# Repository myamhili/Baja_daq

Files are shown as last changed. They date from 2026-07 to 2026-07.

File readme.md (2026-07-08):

# Baja SAE Central Data Acquisition (DAQ) Node

A custom, ruggedized telemetry and data logging PCB engineered for the University of Waterloo Baja SAE racing vehicle. 

Unlike standard microcontroller breakout boards, this DAQ node is designed to survive the harsh electrical and mechanical environment of an automotive chassis. It features a 4-layer load-dump protected layout, dedicated hardware for high-speed logging, and a real-time FreeRTOS firmware architecture.

baja_daq

bajafirmwarepic
LL9DJzj04BtlhnXn9L0uzD93XS64HbL8iSs7r5JLr1b_DFQkjJDBe5N_UtVN8GcNnBFllT6RDtF1WbPStobffIEunDy8QN87qzRs6xG49p2rH5cno67nJFQvfOrIl6xrW1PxA4q_64rQSddrUakbeAuxEg1mWokpQNKD5NPCIWrOhh4cECf9ix7m0HweQKild-d12H_1NmNmFKcl89qdIvq

## ⚙️ Hardware Architecture
* **Microcontroller:** STM32F405RGTx (ARM Cortex-M4) handling real-time sensor polling and SDIO data pipelines.
* **PCB Stackup:** 4-Layer board (Signal, Solid Ground, Split Power, Signal) optimized for signal integrity, return paths, and thermal dissipation.

## 🔋 Automotive-Grade Power System
The board interfaces directly with the vehicle's 12V starter battery and is hardened against off-road electrical surges:
* **Surge Protection:** Input clamped by an SMAJ15A TVS Diode with localized solid copper pour spillways to instantly shunt 60V load dumps to the ground plane.
* **Analog Rail (5V):** L7805 linear regulator feeding suspension and rotary sensors with a clean, heavily filtered reference voltage.
* **Digital Rail (3.3V):** AMS1117 LDO isolated with dedicated bulk tantalum/ceramic decoupling arrays to prevent STM32 brownouts under severe chassis vibration.

## 📡 Sensor & Communication Interfaces
* **Vehicle Network:** CAN Bus (TJA1051T transceiver) acting as a non-blocking broadcast node for dashboard telemetry, timed via an 8MHz external crystal.
* **Inertial Tracking:** On-board 6-axis IMU (ISM330DHCX) communicating via high-speed SPI.
* **Telemetry Logging:** MicroSD card slot wired via 4-bit SDIO with 47k pull-up stability arrays for reliable 100Hz writes.
* **External I/O (Locking Molex Connectors):** * Front & Rear Suspension Travel (Generic 3-pin ADC)
    * Engine & Secondary CVT RPM (Hardware Timers / Input Capture)
    * Belt Temperature Probes (I2C)

## 💻 Firmware Design (FreeRTOS)
The system runs a custom C firmware utilizing the STM32 HAL and CMSIS-RTOS.
* **Decoupled Logging:** A high-priority sensor task handles SPI/I2C polling and mathematically derives ground speed from timer deltas. Data is formatted and pushed to a FreeRTOS queue.
* **Non-Blocking File I/O:** A lower-priority FatFs SD Writer task pulls from the queue to write to the MicroSD card, ensuring that standard file-system latency does not freeze the 100Hz real-time data gathering loop.
* **Data Protection:** Implements an automated 15-minute file rotation state machine to prevent total file corruption in the event of a sudden power loss or rollover.

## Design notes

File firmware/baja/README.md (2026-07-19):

# Baja DAQ firmware

The firmware samples vehicle data at 100 Hz. Logging starts at 800 RPM, stops
after RPM remains below 500 for one second, rotates files every 15 minutes, and
syncs the active file at least once per second. Existing `RUN_####.CSV` files
are never overwritten.

## Sensor interfaces

- MLX90614 object temperature: I2C1, address `0x5A`, PB6/PB7, 100 kHz.
- ISM330DHCX: SPI1 mode 0, PB1 chip select, 104 Hz, +/-4 g and +/-500 dps.
- Suspension position: ADC1 channels 2 and 3 with a 32-sample startup zero.
- Engine and secondary speed: TIM5 input capture with a 500 ms pulse timeout.

CSV `Sensor_Status` bit 0 marks temperature valid and bit 1 marks IMU data
valid. Invalid values must be ignored even if the numeric field contains the
last successful sample.

## CAN frames

- `0x100`, 100 Hz: engine RPM (big-endian uint16), speed, temperature, flags.
  Temperature `0xFF` means invalid. Flag bits 0-3 are high temperature, high
  RPM, temperature invalid, and IMU invalid.
- `0x101`, 1 Hz: saturated uint8 counters for queue drops, SD mount/write/sync
  failures, MLX failures, IMU failures, CAN drops, and CAN bus-off events.

CAN is configured for 333.333 kbit/s from the 16 MHz APB1 clock.

## Bench validation

Before vehicle use, verify sensor axis orientation, pulses per revolution,
gearbox ratio, temperature field of view, CAN bitrate, SD-card removal, and
sudden-power-loss recovery on the assembled board.

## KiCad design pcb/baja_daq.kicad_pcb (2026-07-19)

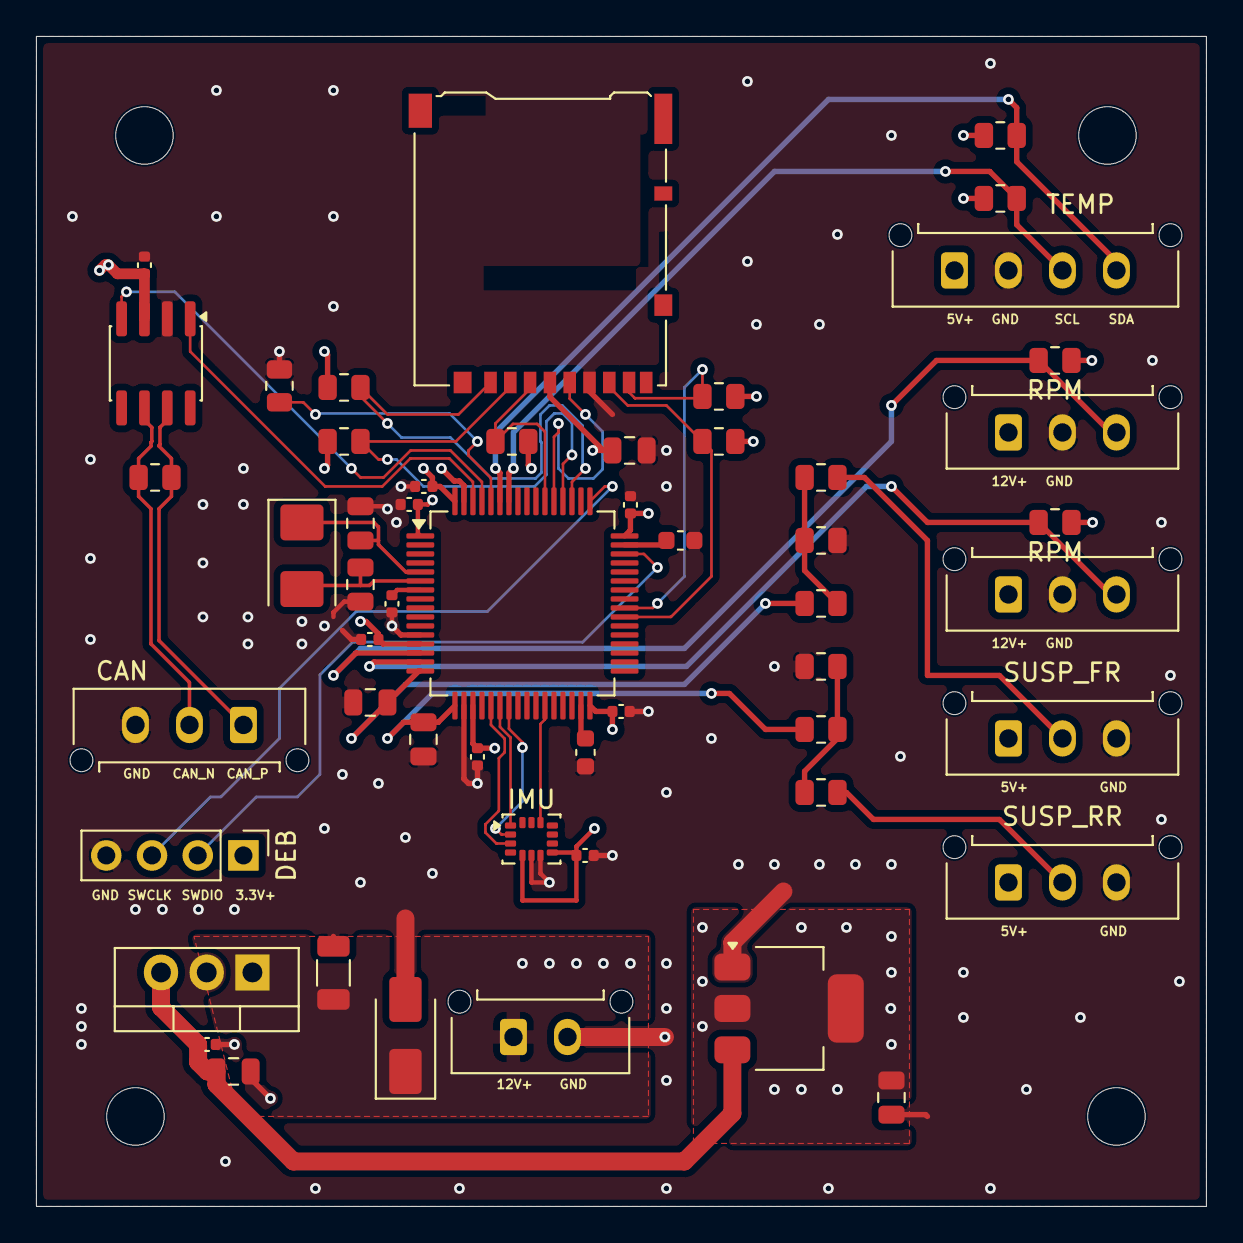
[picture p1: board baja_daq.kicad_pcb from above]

Board: 4 copper layers, 65.0 x 65.0 mm, 57 parts (0 on the bottom side), 36 nets.

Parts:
C1, C2: 22pF; C_0805_2012Metric
C3, C4: 4.7uF; C_0805_2012Metric
C5, C6, C7, C8, C9, C10, C13, C14, C15, C19: 100nF; C_0402_1005Metric
C11, C12: 2.2uF; C_0603_1608Metric
C16, C18: 10uF; C_0805_2012Metric
C17: 10uF; C_1206_3216Metric
C20: 22uF; C_0805_2012Metric
CAN: Conn_01x03; Molex_Micro-Fit_3.0_43650-0315_1x03_P3.00mm_Vertical
D1: SMAJ15A; D_SMA
DEB: Conn_01x04; PinHeader_1x04_P2.54mm_Vertical
H1, H2, H3, H4: MountingHole; MountingHole_3.2mm_M3
IMU: ISM330DHCX; LGA-14_3x2.5mm_P0.5mm_LayoutBorder3x4y
J1: Micro_SD_Card; microSD_HC_Hirose_DM3AT-SF-PEJM5
J3, J4: Conn_01x03; Molex_Micro-Fit_3.0_43650-0315_1x03_P3.00mm_Vertical
J7: Conn_01x02; Molex_Micro-Fit_3.0_43650-0215_1x02_P3.00mm_Vertical
R1: 10k; R_0805_2012Metric
R2, R3, R4, R5, R6: 47k; R_0805_2012Metric
R7: 120Ω; R_0805_2012Metric
R8, R9: 2.2k; R_0805_2012Metric
R12, R15: 1.7k; R_0805_2012Metric
R13, R16: 3.3k; R_0805_2012Metric
R14, R17: 1k; R_0805_2012Metric
RPM: 10k; R_0805_2012Metric
RPM#2: 10k; R_0805_2012Metric
SUSP_FR: Conn_01x03; Molex_Micro-Fit_3.0_43650-0315_1x03_P3.00mm_Vertical
SUSP_RR: Conn_01x03; Molex_Micro-Fit_3.0_43650-0315_1x03_P3.00mm_Vertical
TEMP: Conn_01x04; Molex_Micro-Fit_3.0_43650-0415_1x04_P3.00mm_Vertical
U1: STM32F405RGTx; LQFP-64_10x10mm_P0.5mm
U2: TJA1051T; SOIC-8_3.9x4.9mm_P1.27mm
U4: L7805; TO-220-3_Vertical
U5: AMS1117-3.3; SOT-223-3_TabPin2
Y1: 8MHz; Crystal_SMD_5032-2Pin_5.0x3.2mm

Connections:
+3V3_DIG: C5.1, C6.1, C7.1, C8.1, C9.1, C10.1, C14.1, C16.1, C20.1, DEB.1, IMU.5, IMU.8, J1.4, R2.1, R3.1, R4.1, R5.1, R6.1, R8.1, R9.1, RPM.1, RPM#2.1, U1.1, U1.13, U1.19, U1.32, U1.48, U1.64, U5.2
+5V_ANA: C15.1, C18.1, C19.1, SUSP_FR.1, SUSP_RR.1, TEMP.1, U2.3, U4.3, U5.3
+12V_BATT: C17.1, D1.1, J3.1, J4.1, J7.1, U4.1
CAN_N: CAN.2, R7.2, U2.6
CAN_P: CAN.1, R7.1, U2.7
GND: C1.2, C2.2, C3.2, C4.2, C5.2, C6.2, C7.2, C8.2, C9.2, C10.2, C11.2, C12.2, C13.2, C14.2, C15.2, C16.2, C17.2, C18.2, C19.2, C20.2, CAN.3, D1.2, DEB.4, IMU.6, IMU.7, J1.6, J3.2, J4.2, J7.2, R1.2, R13.2, R16.2, SUSP_FR.3, SUSP_RR.3, TEMP.2, U1.12, U1.18, U1.63, U2.2, U4.2, U5.1
I2C_SCL: R8.2, TEMP.3, U1.58
I2C_SDA: R9.2, TEMP.4, U1.59
unnamed: R1.1, U1.60
unnamed: DEB.2, U1.46
unnamed: DEB.3, U1.49
unnamed: C1.1, U1.5, Y1.1
unnamed: C2.1, U1.6, Y1.2
unnamed: J1.7, R2.2, U1.39
unnamed: J1.8, R3.2, U1.40
unnamed: J1.1, R4.2, U1.51
unnamed: J1.2, R5.2, U1.52
unnamed: J1.5, U1.53
unnamed: J1.3, R6.2, U1.54
unnamed: U1.62, U2.1
unnamed: U1.61, U2.4
unnamed: C11.1, U1.31
unnamed: C12.1, U1.47
unnamed: C13.1, U1.7
RPM_ENG: J3.3, RPM.2, U1.14
RPM_SEC: J4.3, RPM#2.2, U1.15
SPI_CS: IMU.12, U1.27
SPI_MISO: IMU.1, U1.22
SPI_MOSI: IMU.2, U1.23
SPI_SCK: IMU.3, U1.21
SUSP_FR_DIV: R12.2, R13.1, R14.1
SUSP_FR_FLT: C3.1, R14.2, U1.16
SUSP_FR_RAW: R12.1, SUSP_FR.2
SUSP_RR_DIV: R15.2, R16.1, R17.1
SUSP_RR_FLT: C4.1, R17.2, U1.17
SUSP_RR_RAW: R15.1, SUSP_RR.2

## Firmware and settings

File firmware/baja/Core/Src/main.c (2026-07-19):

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
/* Includes ------------------------------------------------------------------*/
#include "main.h"
#include "cmsis_os.h"
#include "adc.h"
#include "can.h"
#include "dma.h"
#include "fatfs.h"
#include "i2c.h"
#include "iwdg.h"
#include "sdio.h"
#include "spi.h"
#include "tim.h"
#include "gpio.h"
#include "diagnostics.h"


/* USER CODE BEGIN PV */
// --- FreeRTOS Globals ---
QueueHandle_t csvDataQueue;

volatile uint16_t adc_buffer[2]; // DMA buffer for 2 analog channels
uint32_t susp_zero_front_rt = 0;
uint32_t susp_zero_rear_rt = 0;

volatile uint32_t engine_delta_ticks = 0;
volatile uint32_t secondary_delta_ticks = 0;
volatile uint32_t engine_last_pulse_ms = 0;
volatile uint32_t secondary_last_pulse_ms = 0;
static volatile uint32_t engine_last_capture = 0;
static volatile uint32_t secondary_last_capture = 0;
static volatile uint8_t engine_capture_valid = 0;
static volatile uint8_t secondary_capture_valid = 0;

// --- CAN Globals ---
CAN_TxHeaderTypeDef TxHeader;
uint32_t TxMailbox;
uint8_t TxData[8];
/* USER CODE END PV */

void SystemClock_Config(void);
void MX_FREERTOS_Init(void);
/* USER CODE BEGIN 0 */
// --- Initialization Functions ---
void Init_CAN_Broadcast(void) {
    if (HAL_CAN_Start(&hcan1) != HAL_OK ||
        HAL_CAN_ActivateNotification(&hcan1,
                                     CAN_IT_ERROR |
                                     CAN_IT_BUSOFF) != HAL_OK) {
        Error_Handler();
    }

    // Pre-configure the Transmission Header
    TxHeader.StdId = 0x100;           
    TxHeader.ExtId = 0x00;
    TxHeader.RTR = CAN_RTR_DATA;      
    TxHeader.IDE = CAN_ID_STD;        
    TxHeader.DLC = 8;                 
    TxHeader.TransmitGlobalTime = DISABLE;
}

// Called once in main() before FreeRTOS scheduler starts
void Calibrate_Suspension_Zeros(void) {
    uint32_t front_sum = 0U;
    uint32_t rear_sum = 0U;
    uint32_t sample;

    if (HAL_ADC_Start_DMA(&hadc1, (uint32_t *)adc_buffer, 2) != HAL_OK) {
        Error_Handler();
    }
    HAL_Delay(10);
    for (sample = 0U; sample < 32U; sample++) {
        front_sum += adc_buffer[0];
        rear_sum += adc_buffer[1];
        HAL_Delay(1);
    }
    susp_zero_front_rt = front_sum / 32U;
    susp_zero_rear_rt = rear_sum / 32U;
}

void Start_Timing_Inputs(void) {
    if (HAL_TIM_IC_Start_IT(&htim5, TIM_CHANNEL_1) != HAL_OK) {
        Error_Handler();
    }
    if (HAL_TIM_IC_Start_IT(&htim5, TIM_CHANNEL_2) != HAL_OK) {
        Error_Handler();
    }
}
/* USER CODE END 0 */

/**
  * @brief  The application entry point.
  * @retval int
  */
int main(void)
{

  /* MCU Configuration--------------------------------------------------------*/

  /* Reset of all peripherals, Initializes the Flash interface and the Systick. */
  HAL_Init();

  /* Configure the system clock */
  SystemClock_Config();

  /* Initialize all configured peripherals */
  MX_GPIO_Init();
  MX_DMA_Init();
  MX_ADC1_Init();
  MX_CAN1_Init();
  MX_I2C1_Init();
  MX_SDIO_SD_Init();
  MX_SPI1_Init();
  MX_TIM5_Init();
  MX_FATFS_Init();
  MX_IWDG_Init();
  /* USER CODE BEGIN 2 */
  Calibrate_Suspension_Zeros();
  Start_Timing_Inputs();
  Init_CAN_Broadcast();
  /* USER CODE END 2 */

  /* Call init function for freertos objects (in cmsis_os2.c) */
  MX_FREERTOS_Init();

  /* Start scheduler */
  osKernelStart();

  /* We should never get here as control is now taken by the scheduler */

  /* Infinite loop */
  /* USER CODE BEGIN WHILE */
  while (1)
  {
    /* USER CODE END WHILE */

    /* USER CODE BEGIN 3 */
  }
  /* USER CODE END 3 */
}

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
/* USER CODE BEGIN 4 */
void HAL_TIM_IC_CaptureCallback(TIM_HandleTypeDef *htim)
{
  uint32_t capture;

  if (htim->Instance != TIM5) {
    return;
  }

  if (htim->Channel == HAL_TIM_ACTIVE_CHANNEL_1) {
    capture = HAL_TIM_ReadCapturedValue(htim, TIM_CHANNEL_1);
    if (engine_capture_valid != 0U) {
      engine_delta_ticks = capture - engine_last_capture;
    }
    engine_last_capture = capture;
    engine_last_pulse_ms = HAL_GetTick();
    engine_capture_valid = 1U;
  } else if (htim->Channel == HAL_TIM_ACTIVE_CHANNEL_2) {
    capture = HAL_TIM_ReadCapturedValue(htim, TIM_CHANNEL_2);
    if (secondary_capture_valid != 0U) {
      secondary_delta_ticks = capture - secondary_last_capture;
    }
    secondary_last_capture = capture;
    secondary_last_pulse_ms = HAL_GetTick();
    secondary_capture_valid = 1U;
  }
}

void HAL_CAN_ErrorCallback(CAN_HandleTypeDef *hcan)
{
  uint32_t error = HAL_CAN_GetError(hcan);

  if ((error & HAL_CAN_ERROR_BOF) != 0U) {
    g_diagnostics.can_bus_offs++;
    HAL_CAN_Stop(hcan);
    HAL_CAN_Start(hcan);
    HAL_CAN_ActivateNotification(hcan,
                                  CAN_IT_ERROR |
                                  CAN_IT_BUSOFF);
  }
}

/* USER CODE END 4 */

/**
  * @brief  Period elapsed callback in non blocking mode
  * @note   This function is called  when TIM6 interrupt took place, inside
  * HAL_TIM_IRQHandler(). It makes a direct call to HAL_IncTick() to increment
  * a global variable "uwTick" used as application time base.
  * @param  htim : TIM handle
  * @retval None
  */
void HAL_TIM_PeriodElapsedCallback(TIM_HandleTypeDef *htim)
{
  if (htim->Instance == TIM6)
  {
    HAL_IncTick();
  }
}

/**
  * @brief  This function is executed in case of error occurrence.
  * @retval None
  */
void Error_Handler(void)
{
  /* USER CODE BEGIN Error_Handler_Debug */
  /* User can add his own implementation to report the HAL error return state */
  __disable_irq();
  while (1)
  {
  }
  /* USER CODE END Error_Handler_Debug */
}
#ifdef USE_FULL_ASSERT
/**
  * @brief  Reports the name of the source file and the source line number
  *         where the assert_param error has occurred.
  * @param  file: pointer to the source file name
  * @param  line: assert_param error line source number
  * @retval None
  */
void assert_failed(uint8_t *file, uint32_t line)
{
  /* USER CODE BEGIN 6 */
  /* User can add his own implementation to report the file name and line number,
     ex: printf("Wrong parameters value: file %s on line %d\r\n", file, line) */
  /* USER CODE END 6 */
}
#endif /* USE_FULL_ASSERT */

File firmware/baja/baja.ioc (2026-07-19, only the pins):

Mcu.UserName=STM32F405RGTx
PA0-WKUP.Signal=S_TIM5_CH1
PA1.Signal=S_TIM5_CH2
PA13.Signal=SYS_JTMS-SWDIO
PA14.Signal=SYS_JTCK-SWCLK
PA2.Signal=ADCx_IN2
PA3.Signal=ADCx_IN3
PA5.Signal=SPI1_SCK
PA6.Signal=SPI1_MISO
PA7.Signal=SPI1_MOSI
PB1.GPIO_Label=SPI_CS
PB1.Signal=GPIO_Output
PB6.Signal=I2C1_SCL
PB7.Signal=I2C1_SDA
PB8.Signal=CAN1_RX
PB9.Signal=CAN1_TX
PC10.Signal=SDIO_D2
PC11.Signal=SDIO_D3
PC12.Signal=SDIO_CK
PC8.Signal=SDIO_D0
PC9.Signal=SDIO_D1
PD2.Signal=SDIO_CMD
PH0-OSC_IN.Signal=RCC_OSC_IN
PH1-OSC_OUT.Signal=RCC_OSC_OUT

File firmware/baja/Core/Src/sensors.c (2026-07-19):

#include "sensors.h"
#include "i2c.h"
#include "spi.h"
#include <math.h>

#define MLX90614_ADDRESS          (0x5AU << 1)
#define MLX90614_OBJECT_TEMP_REG  0x07U
#define MLX90614_RETRIES          3U
#define MLX90614_TIMEOUT_MS       20U

#define ISM330_WHO_AM_I_REG       0x0FU
#define ISM330_WHO_AM_I_VALUE     0x6BU
#define ISM330_CTRL1_XL_REG       0x10U
#define ISM330_CTRL2_G_REG        0x11U
#define ISM330_CTRL3_C_REG        0x12U
#define ISM330_OUTX_L_G_REG       0x22U
#define ISM330_SPI_READ           0x80U
#define ISM330_SPI_TIMEOUT_MS     20U
#define RAD_TO_DEG                57.2957795f

static uint8_t Calculate_PEC(const uint8_t *data, uint32_t length)
{
  uint8_t crc = 0U;
  uint32_t i;
  uint8_t bit;

  for (i = 0U; i < length; i++) {
    crc ^= data[i];
    for (bit = 0U; bit < 8U; bit++) {
      crc = (crc & 0x80U) ? (uint8_t)((crc << 1U) ^ 0x07U)
                          : (uint8_t)(crc << 1U);
    }
  }
  return crc;
}

bool MLX90614_Init(void)
{
  return HAL_I2C_IsDeviceReady(&hi2c1, MLX90614_ADDRESS,
                               MLX90614_RETRIES, MLX90614_TIMEOUT_MS) == HAL_OK;
}

bool MLX90614_ReadObjectTemp(float *temperature_c)
{
  uint8_t response[3];
  uint8_t pec_data[5];
  uint16_t raw;
  uint32_t attempt;

  if (temperature_c == NULL) {
    return false;
  }

  for (attempt = 0U; attempt < MLX90614_RETRIES; attempt++) {
    if (HAL_I2C_Mem_Read(&hi2c1, MLX90614_ADDRESS,
                         MLX90614_OBJECT_TEMP_REG, I2C_MEMADD_SIZE_8BIT,
                         response, sizeof(response), MLX90614_TIMEOUT_MS) != HAL_OK) {
      continue;
    }

    pec_data[0] = MLX90614_ADDRESS;
    pec_data[1] = MLX90614_OBJECT_TEMP_REG;
    pec_data[2] = (uint8_t)(MLX90614_ADDRESS | 1U);
    pec_data[3] = response[0];
    pec_data[4] = response[1];
    if (Calculate_PEC(pec_data, sizeof(pec_data)) != response[2]) {
      continue;
    }

    raw = (uint16_t)response[0] | ((uint16_t)response[1] << 8U);
    if ((raw & 0x8000U) != 0U) {
      continue;
    }

    *temperature_c = ((float)raw * 0.02f) - 273.15f;
    return true;
  }

  return false;
}

static bool ISM330_Transfer(uint8_t reg, uint8_t *data, uint16_t length, bool read)
{
  HAL_StatusTypeDef status;
  uint8_t command = read ? (uint8_t)(reg | ISM330_SPI_READ) : reg;

  HAL_GPIO_WritePin(SPI_CS_GPIO_Port, SPI_CS_Pin, GPIO_PIN_RESET);
  status = HAL_SPI_Transmit(&hspi1, &command, 1U, ISM330_SPI_TIMEOUT_MS);
  if (status == HAL_OK) {
    status = read ? HAL_SPI_Receive(&hspi1, data, length, ISM330_SPI_TIMEOUT_MS)
                  : HAL_SPI_Transmit(&hspi1, data, length, ISM330_SPI_TIMEOUT_MS);
  }
  HAL_GPIO_WritePin(SPI_CS_GPIO_Port, SPI_CS_Pin, GPIO_PIN_SET);

  return status == HAL_OK;
}

static bool ISM330_WriteRegister(uint8_t reg, uint8_t value)
{
  return ISM330_Transfer(reg, &value, 1U, false);
}

static bool ISM330_ReadRegister(uint8_t reg, uint8_t *value)
{
  return ISM330_Transfer(reg, value, 1U, true);
}

bool ISM330DHCX_Init(void)
{
  uint8_t who_am_i = 0U;

  HAL_GPIO_WritePin(SPI_CS_GPIO_Port, SPI_CS_Pin, GPIO_PIN_SET);
  if (!ISM330_ReadRegister(ISM330_WHO_AM_I_REG, &who_am_i) ||
      who_am_i != ISM330_WHO_AM_I_VALUE) {
    return false;
  }

  /* 104 Hz, +/-4 g; 104 Hz, +/-500 dps; block update and auto-increment. */
  return ISM330_WriteRegister(ISM330_CTRL3_C_REG, 0x44U) &&
         ISM330_WriteRegister(ISM330_CTRL1_XL_REG, 0x48U) &&
         ISM330_WriteRegister(ISM330_CTRL2_G_REG, 0x44U);
}

bool ISM330DHCX_ReadOrientation(int16_t *roll_deg, int16_t *pitch_deg,
                               int16_t *z_mg)
{
  uint8_t raw_data[12];
  int16_t accel_x_raw;
  int16_t accel_y_raw;
  int16_t accel_z_raw;
  float accel_x_mg;
  float accel_y_mg;
  float accel_z_mg;
  float roll;
  float pitch;

  if (roll_deg == NULL || pitch_deg == NULL || z_mg == NULL ||
      !ISM330_Transfer(ISM330_OUTX_L_G_REG, raw_data, sizeof(raw_data), true)) {
    return false;
  }

  accel_x_raw = (int16_t)((uint16_t)raw_data[6] | ((uint16_t)raw_data[7] << 8U));
  accel_y_raw = (int16_t)((uint16_t)raw_data[8] | ((uint16_t)raw_data[9] << 8U));
  accel_z_raw = (int16_t)((uint16_t)raw_data[10] | ((uint16_t)raw_data[11] << 8U));
  accel_x_mg = (float)accel_x_raw * 0.122f;
  accel_y_mg = (float)accel_y_raw * 0.122f;
  accel_z_mg = (float)accel_z_raw * 0.122f;

  roll = atan2f(accel_y_mg, accel_z_mg) * RAD_TO_DEG;
  pitch = atan2f(-accel_x_mg,
                 sqrtf((accel_y_mg * accel_y_mg) +
                       (accel_z_mg * accel_z_mg))) * RAD_TO_DEG;

  *roll_deg = (int16_t)roll;
  *pitch_deg = (int16_t)pitch;
  *z_mg = (int16_t)accel_z_mg;
  return true;
}

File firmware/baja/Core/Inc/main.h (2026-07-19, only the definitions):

#define ENGINE_PPR            2.0f         // Pulses Per Revolution
#define SECONDARY_PPR         4.0f         
#define GEARBOX_RATIO         8.5f         
#define TIRE_DIAMETER_M       0.5842f      
#define BELT_TEMP_LIMIT_C     88.0f        
#define ENGINE_START_RPM      800.0f       
#define ENGINE_STOP_RPM       500.0f
#define ENGINE_STOP_DELAY_MS  1000U
#define RPM_TIMEOUT_MS        500U
#define FILE_ROTATION_MS      900000
#define CSV_QUEUE_DEPTH       32U
#define SD_SYNC_INTERVAL_MS   1000U
#define SD_SYNC_RECORDS       100U
#define SENSOR_STATUS_TEMP_VALID  (1U << 0)
#define SENSOR_STATUS_IMU_VALID   (1U << 1)
#define SPI_CS_Pin GPIO_PIN_1
#define SPI_CS_GPIO_Port GPIOB

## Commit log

2026-06-19 modified layer3 (power split)
    [baja_daq.kicad_pcb]
2026-07-19 updated firmware
    [baja_daq.kicad_pcb]

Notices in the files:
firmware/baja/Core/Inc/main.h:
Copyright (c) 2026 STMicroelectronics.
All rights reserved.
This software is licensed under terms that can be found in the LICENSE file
